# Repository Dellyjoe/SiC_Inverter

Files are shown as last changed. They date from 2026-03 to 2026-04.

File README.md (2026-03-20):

# SiC-Based Modular Inverter System
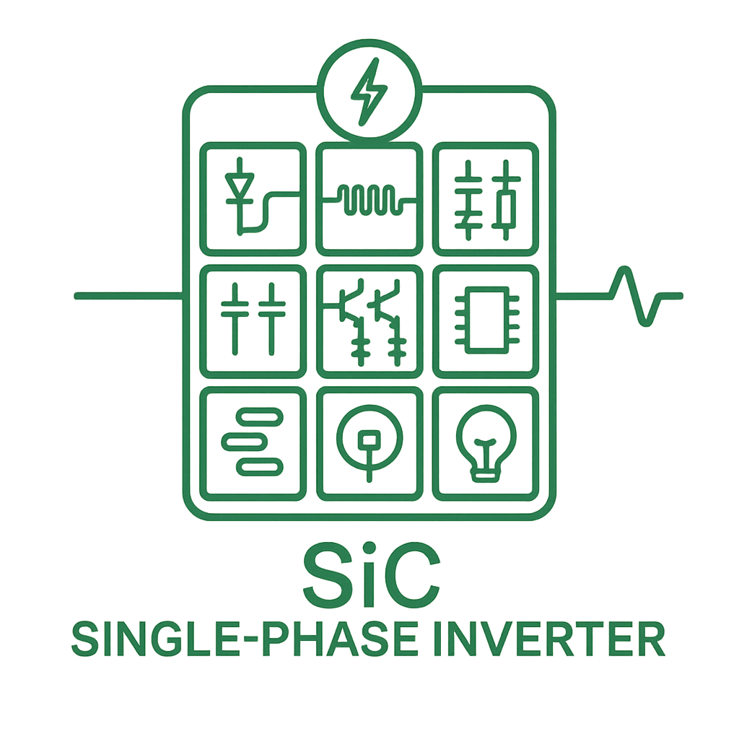
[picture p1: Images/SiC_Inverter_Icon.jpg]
SiC Icon


## Table of Contents
1. [Project Overview](#1-project-overview)  
2. [System Architecture](#2-system-architecture)  
   - [EMI Input Filter](#21-emi-input-filter)  
   - [Pre‑Charge & Inrush Limiting](#22-pre-charge--inrush-limiting)  
   - [DC‑Link Capacitor Network](#23-dc-link-capacitor-network)  
   - [Inverter Power Stage](#24-inverter-power-stage)  
   - [Output LCL Filter](#25-output-lcl-filter)  
3. [Electrical Specifications](#3-electrical-specifications)  
4. [Development Tools & Equipment](#4-development-tools--equipment)  
5. [Current Status](#5-current-status)  
6. [System Block Diagram](#6-system-block-diagram)

---

## 1. Project Overview

This project is a **modular, SiC‑based single‑phase inverter system** designed using professional engineering practices and a clean, hierarchical architecture. Each functional block is implemented as its own PCB, enabling:

- **Modularity** — swap, upgrade, or debug subsystems independently  
- **Scalability** — expand to higher power levels or new control architectures  
- **Serviceability** — isolate issues quickly during bring‑up  
- **Educational clarity** — each PCB teaches a specific power‑electronics concept  

Key design principles:

- **Hierarchical schematics** (KiCad 9)  
- **Modular PCBs** (EMI filter, pre‑charge, DC‑link, inverter legs, LCL filter, power supplies, controller)  
- **High‑performance SiC MOSFETs** for fast switching and low losses  
- **Low‑inductance DC‑link layout**  
- **Safe, lab‑friendly bring‑up** (initially 60 VDC)  

The long‑term goal is a **flexible, open inverter platform** suitable for experimentation, research, and future expansion.

---

## 2. System Architecture

The inverter is divided into well‑defined functional blocks.

### 2.1 EMI Input Filter
- Differential‑mode LC filter  
  - **L_DM:** `2300HT-470-H-RC`  
  - **C_IN:** `R71PI410050H6K`  
- Common‑mode choke: `7448258022`  
- Provides clean, low‑noise DC to downstream stages  
- **Outputs:** `BUS+_Filtered`, `BUS-_Filtered`

---

### 2.2 Pre‑Charge & Inrush Limiting
- Limits inrush current to **~5 A**  
- Uses an **80 Ω** pre‑charge resistor  
- MOSFET/relay bypass for full‑power operation  
- Interfaces between EMI filter and DC‑link  
- **Outputs:** `DC+`, `DC−`

---

### 2.3 DC‑Link Capacitor Network
- **Bulk Storage:** 220 µF electrolytic (10 × `ESH226M500AL4AA`)  
- **High‑Frequency Film:** 10 µF polypropylene (5 × `MKP1848C52050JK2`)  
- Provides:
  - Energy storage  
  - Low‑impedance switching current path  
  - Reduced ripple and overshoot  

---

### 2.4 Inverter Power Stage
- **Topology:** Full‑bridge using SiC MOSFET half‑bridge legs  
- **Switching Devices:** 4 × Wolfspeed `C3M0025065K`  
- **Gate Drivers:** 4 × TI `UCC21710QDWRQ1` isolated drivers  
- **Sensing:** Placeholders for output current and DC bus voltage (future work)  
- **Control:** PWM interface for microcontroller or DSP  

---

### 2.5 Output LCL Filter
- Shapes PWM into low‑distortion 60 Hz AC  
- Reduces switching ripple and protects the load  
- **Components:**
  - **Series Inductors:**  
    - `L1`: 470 µH (`Bourns 1140-471K-RC`)  
    - `L2`: 470 µH (`Bourns 1140-471K-RC`)  
  - **Shunt Capacitor:**  
    - `C_F`: 6.8 µF, 305 Vac MKP (`KEMET C4AF9BW4680T3FK`)  
  - **Damping Resistor:**  
    - `R_D`: ~10 Ω, ≥3 W (`TE 3-2176794-3`)  
- **Design Target:**  
  - Resonant frequency ≈ 2 kHz  
  - Damped to avoid resonance peaking  

---

## 3. Electrical Specifications

| Parameter | Value | Notes |
|---|---|---|
| **Input Voltage Range** | 335–425 VDC | |
| **Nominal DC Bus Voltage** | 400 VDC | |
| **Output Voltage** | 120 Vrms | Single‑phase AC |
| **Output Frequency** | 60 Hz | |
| **Continuous Power** | 500 W | |
| **Peak Power** | 1 kW | |
| **Continuous Current (RMS)** | 4.1 Arms | Output |
| **Continuous Current (DC)** | 1.25 A | Input at nominal voltage |
| **Switching Frequency** | 40 kHz | Initial target |
| **Target Inrush Current** | < 5 A | Pre‑charge limited |
| **DC‑Link Capacitance** | 220 µF electrolytic + 10 µF film | |
| **Capacitor Voltage Rating** | >500 V | |
| **Output Filter Topology** | LCL | 470 µH – 6.8 µF – 470 µH |

---

## 4. Development Tools & Equipment
- **CAD:** KiCad 9 (hierarchical design)  
- **Version Control:** Git  
- **Documentation:** draw.io, Markdown  
- **Bench Tools:** Oscilloscope, isolated supplies, differential probes  
- *(More tools will be added as the project grows)*  

---

## 5. Current Status

- [x] EMI filter — **Complete**  
- [x] Pre‑charge topology — **Defined**  
- [x] DC‑link architecture — **Defined**  
- [x] KiCad hierarchy — **Modular & clean**  
- [x] Pre‑charge components added  
- [x] DC‑link capacitor bank added  
- [x] Inverter leg schematic started  
- [x] Output LCL filter populated with real parts  
- [x] Inverter + LCL interaction reviewed in simulation  
- [x] Power‑stage support rails (+15V ISO, +3V3 logic)  
- [x] Controller selected  
- [ ] Controller wiring  
- [ ] Layout of sub‑PCBs  
- [ ] System wiring and integration  

---

## 6. System Block Diagram

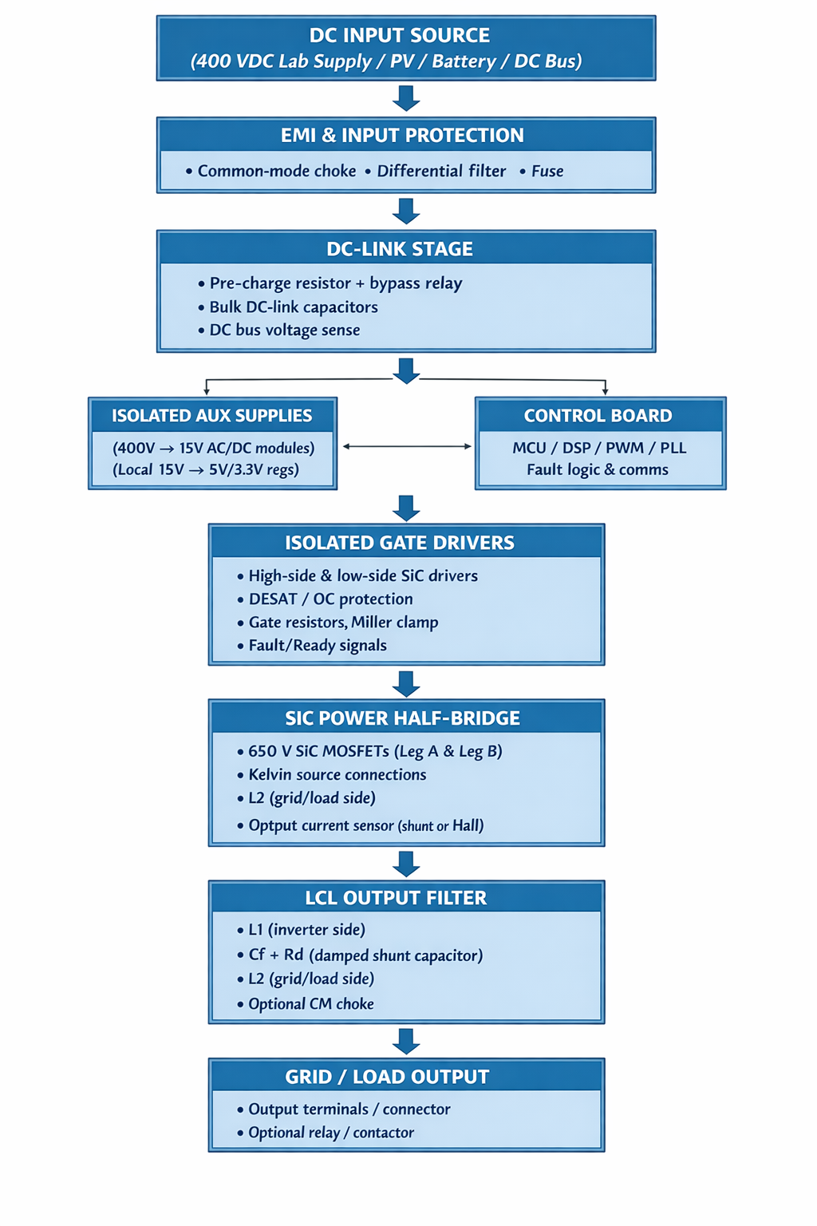
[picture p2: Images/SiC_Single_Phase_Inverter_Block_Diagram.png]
Block Diagram


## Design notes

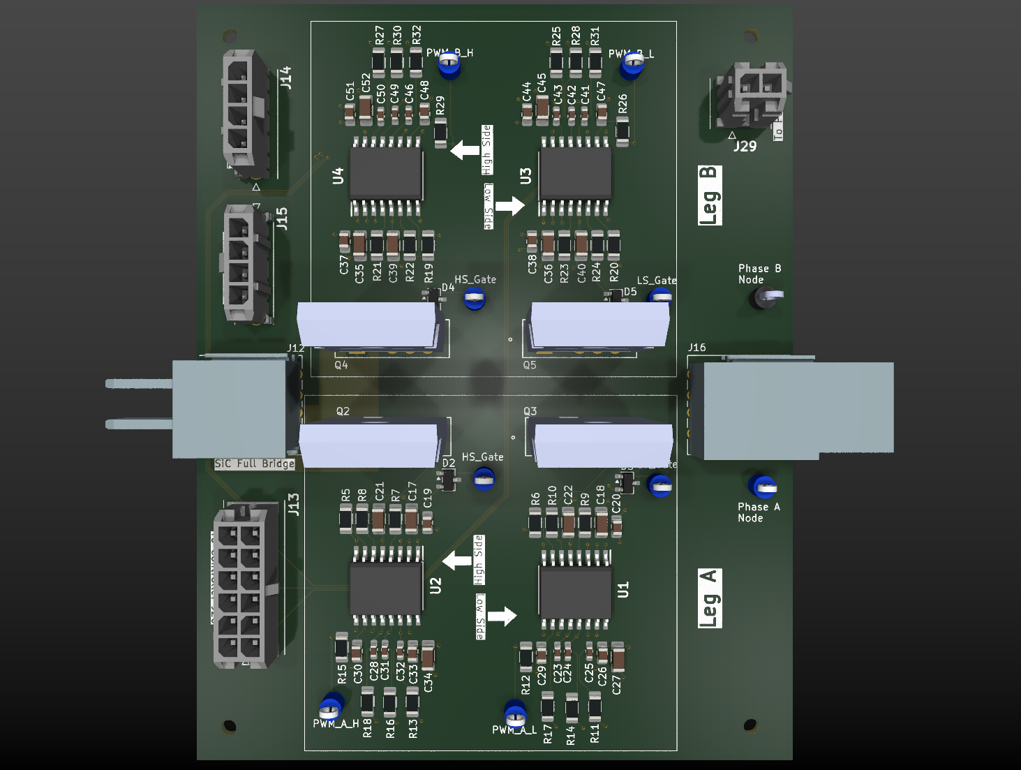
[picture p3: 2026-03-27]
Images/DC_input_Protection_PCB/Full-Bridge_PCB.png

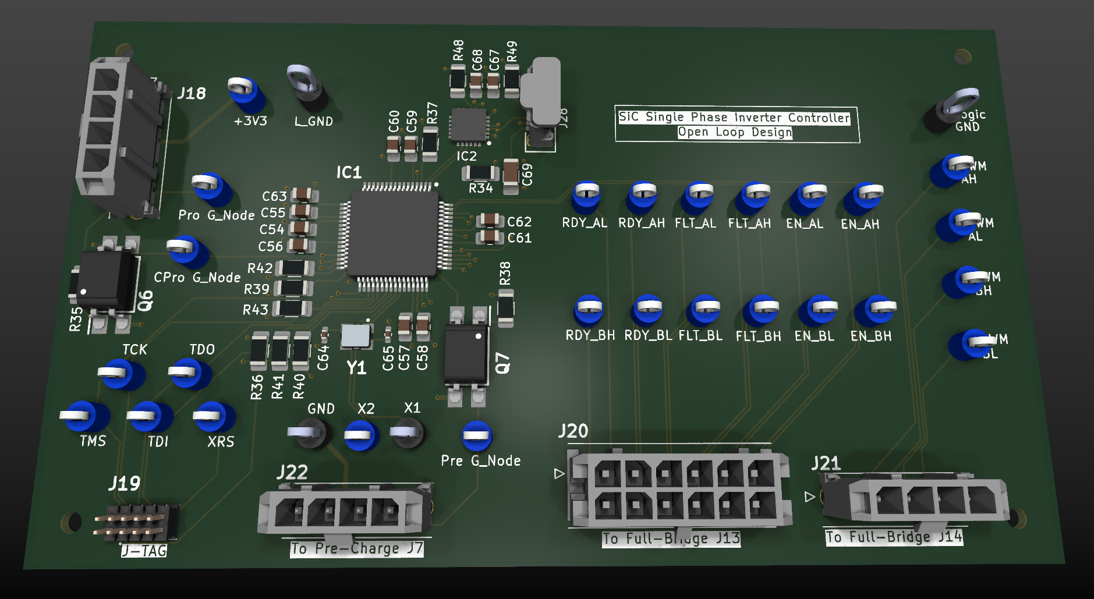
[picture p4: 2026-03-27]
Images/DC_input_Protection_PCB/Controller_Board_PCB.png

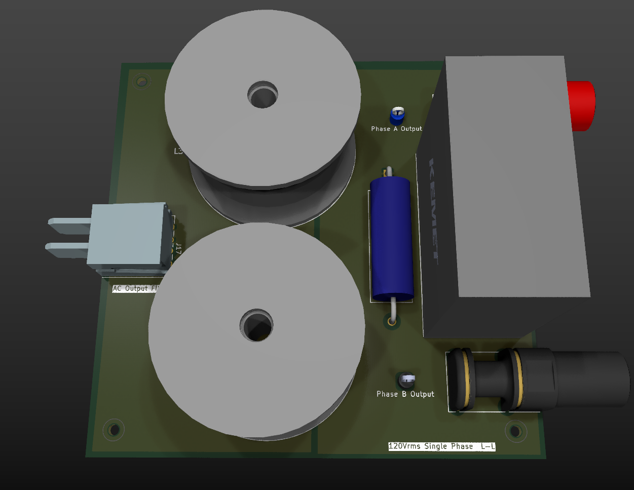
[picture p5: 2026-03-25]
Images/DC_input_Protection_PCB/AC_Output_Filter.png

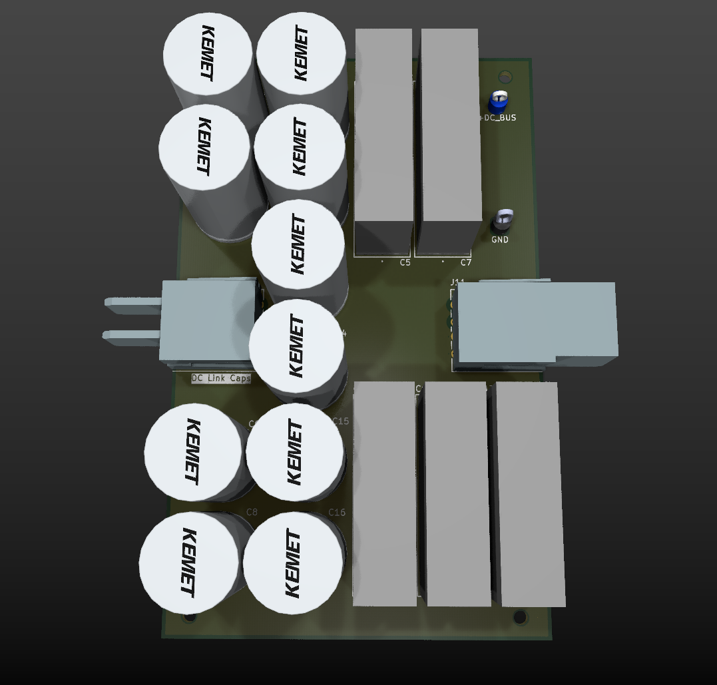
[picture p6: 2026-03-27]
Images/DC_input_Protection_PCB/DC_Link_caps.png

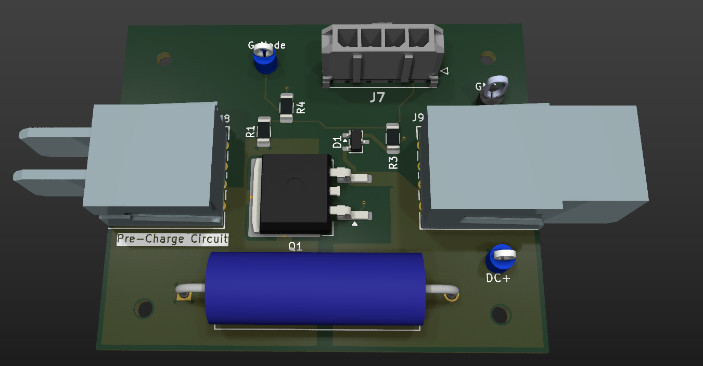
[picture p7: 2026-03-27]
Images/DC_input_Protection_PCB/Pre_Charge_Circuit.png

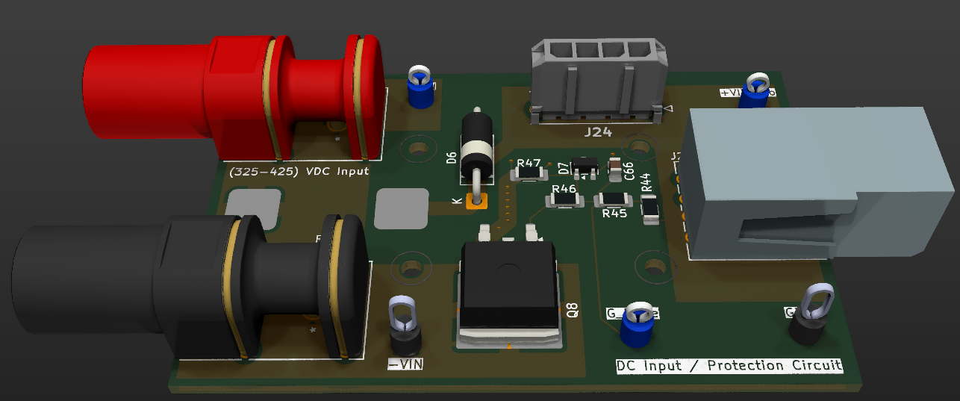
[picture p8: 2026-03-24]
Images/DC_input_Protection_PCB/DC_Input_ProtectionB1.0.png

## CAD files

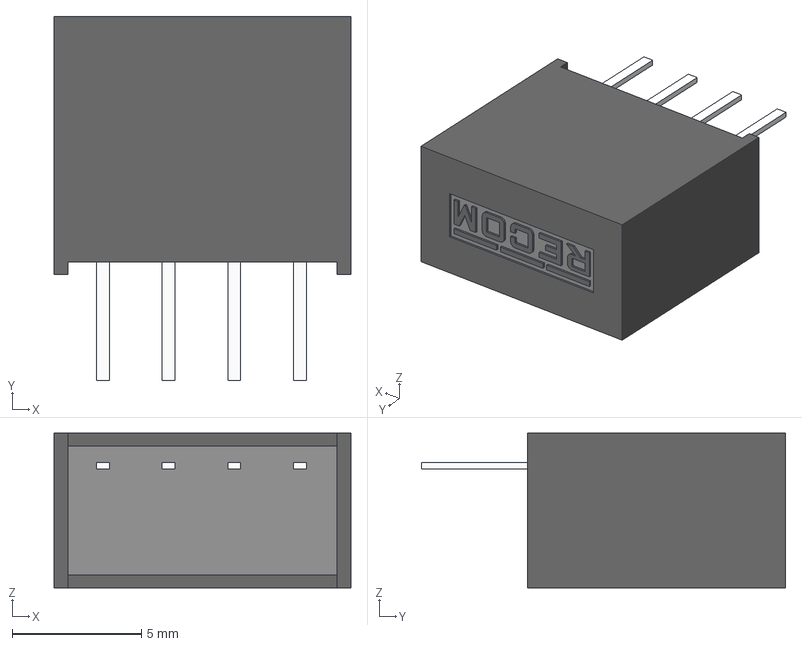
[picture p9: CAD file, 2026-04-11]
Schematics/3d-models/RO-153.3S_H.stp
11.5 x 14.1 x 6.00 mm

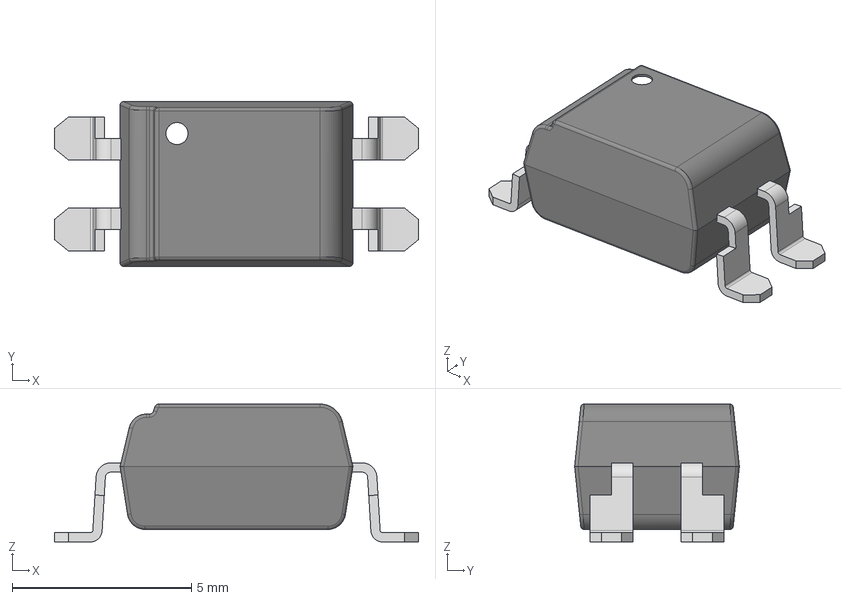
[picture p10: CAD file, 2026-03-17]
Schematics/Sub_PCB_Sheets/AC_Output_Filter/3d-models/PC817X1CSP9F.stp
10.2 x 4.60 x 3.85 mm

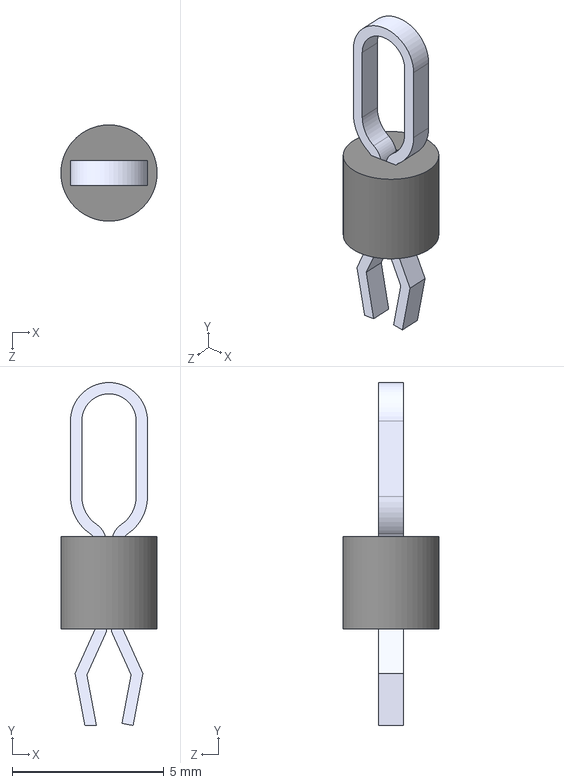
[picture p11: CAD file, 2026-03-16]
Schematics/Sub_PCB_Sheets/AC_Output_Filter/3d-models/5281.stp
3.17 x 11.3 x 3.17 mm

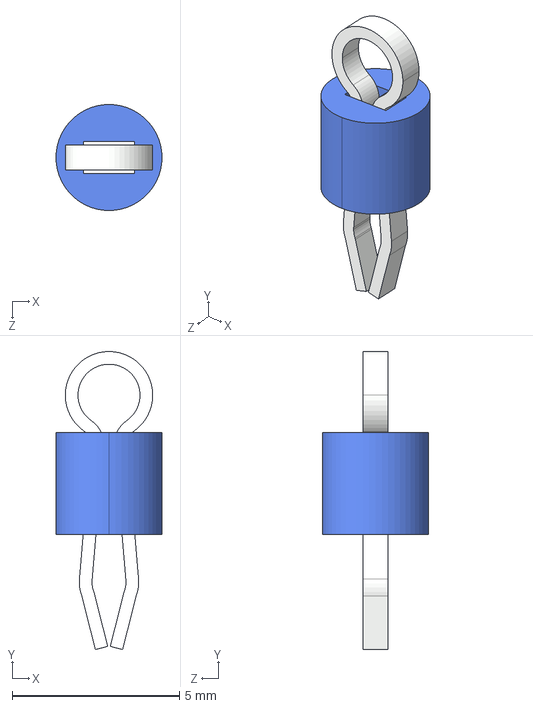
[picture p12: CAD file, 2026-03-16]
Schematics/Sub_PCB_Sheets/DC_Link_Caps/3d-models/5277.stp
3.17 x 8.92 x 3.17 mm

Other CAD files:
Schematics/3d-models/43045-0212.stp
Schematics/Sub_PCB_Sheets/AC_Output_Filter/3d-models/0464369202.stp
Schematics/Sub_PCB_Sheets/AC_Output_Filter/3d-models/0464379202.stp
Schematics/Sub_PCB_Sheets/AC_Output_Filter/3d-models/105133-0011.stp
Schematics/Sub_PCB_Sheets/AC_Output_Filter/3d-models/1140-471K-RC.stp
Schematics/Sub_PCB_Sheets/AC_Output_Filter/3d-models/2300HT-470-H-RC.stp
Schematics/Sub_PCB_Sheets/AC_Output_Filter/3d-models/43045-1212.stp
Schematics/Sub_PCB_Sheets/AC_Output_Filter/3d-models/43650-0418.stp
Schematics/Sub_PCB_Sheets/AC_Output_Filter/3d-models/66.9040-21_Black.stp
Schematics/Sub_PCB_Sheets/AC_Output_Filter/3d-models/66.9040-22_Red.stp
Schematics/Sub_PCB_Sheets/AC_Output_Filter/3d-models/ABM8-20.000MHZ-B2-T.stp
Schematics/Sub_PCB_Sheets/AC_Output_Filter/3d-models/C3M0025065K.stp
Schematics/Sub_PCB_Sheets/AC_Output_Filter/3d-models/C4AF9BW4680T3FK.stp
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

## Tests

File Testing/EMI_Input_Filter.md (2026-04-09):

# EMI Input Filter – Testing Document

## 1. Overview

This document captures the test procedure, setup, and measured performance of the EMI Input Filter used between `+VIN_EMI` and `BUS+_Filtered`.  
The filter consists of:

- **L1 = 47 µH** (series)
- **C1 = 1 µF** (shunt to GND)
- **L2 = 2.2 mH** (series)(CMC)

This forms a two‑stage differential‑mode LC low‑pass filter intended to suppress inverter switching noise from propagating back toward the DC source.

---

## 2. Test Equipment

- **Function Generator**
  - Sine wave output
  - 1 Vpp amplitude
  - Output load set to **High‑Z / 1 MΩ**
- **Oscilloscope**
  - Two channels (CH1 = Vin, CH2 = Vout)
  - DC coupling
  - Matching probe attenuation (1×)
---

## 3. Test Setup

### Connections

- Function Gen `+` → `+VIN_EMI`
- Function Gen `−` → GND
- Scope CH1 → `+VIN_EMI`
- Scope CH2 → `BUS+_Filtered`
- Scope grounds → GND

### Notes
- Verify the function generator produces the correct amplitude by connecting it directly to the scope before testing the filter.
---

## 4. Test Procedure

1. **Baseline Verification**
   - Set function generator to **1 kHz, 1 Vpp**.
   - Confirm **Vin ≈ Vout** (flat passband behavior).

2. **Frequency Sweep**
   - Keep amplitude at **1 Vpp**.
   - Measure Vin and Vout at the following frequencies:
     - 0.01 kHz  
     - 0.1 kHz  
     - 1 kHz  
     - 10 kHz  
     - 50 kHz  
     - 100 kHz  
     - 200 kHz  
     - 500 kHz  
     - 1000 kHz (1 MHz)

3. **Record Data**
   - Capture Vin (Vpp), Vout (Vpp), and compute attenuation.

---

## 5. Measured Results

### Raw Data

| Freq (kHz) | Vin (Vpp) | Vout (Vpp) |
|---:|---|---|
| 0.01 | 1.000 V | 1.000 V |
| 0.1 | 0.983 V | 0.999 V |
| 1 | 0.378 V | 0.378 V |
| 10 | 0.034 V | 0.042 V |
| 50 | 0.030 V | 0.010 V |
| 100 | 0.071 V | 0.0057 V |
| 200 | 0.148 V | 0.0020 V |
| 500 | 0.390 V | 0.0015 V |
| 1000 | 0.810 V | 0.0012 V |

### Calculated Attenuation

| Freq (kHz) | Vout/Vin | Attenuation (dB) |
|---:|---|---|
| 0.01 | 1.00 | 0.0 dB |
| 0.1 | 1.02 | +0.2 dB |
| 1 | 1.00 | 0.0 dB |
| 10 | 1.24 | +1.9 dB |
| 50 | 0.33 | −9.6 dB |
| 100 | 0.08 | −22.0 dB |
| 200 | 0.0135 | −37.4 dB |
| 500 | 0.00385  | −48.3 dB |
| 1000 | 0.00148  | −56.6 dB |

---

## 6. Interpretation

### Passband (0–1 kHz)
- Filter is flat and stable.
- No significant attenuation.
- Suitable for inverter low‑frequency bus ripple and control‑loop dynamics.

### Transition Region (10–50 kHz)
- Begins attenuating around 10–20 kHz.
- ~−10 dB by 50 kHz.

### Stopband (100 kHz–1 MHz)
- Strong attenuation:
  - ~−22 dB at 100 kHz  
  - ~−37 dB at 200 kHz  
  - ~−48 dB at 500 kHz  
  - ~−57 dB at 1 MHz  
---

## 7. Practical Impact on the System

If the inverter produces ~1 Vpp differential‑mode ripple on the DC bus:

- At **50 kHz** → ~0.33 Vpp reaches +VIN_EMI  
- At **100 kHz** → ~80 mVpp  
- At **200 kHz** → ~13 mVpp  
- At **500 kHz** → ~4 mVpp  
- At **1 MHz** → ~1.5 mVpp  

This significantly reduces conducted noise back into the power supply or battery.

---

## 8. Conclusion

The EMI Input Filter performs as designed:

- Flat response in the operating band (0–1 kHz)
- Strong attenuation in the inverter switching band (50–200 kHz)
- Very deep attenuation at high harmonics (500 kHz–1 MHz)

This filter will effectively prevent inverter switching noise from contaminating the upstream DC source.

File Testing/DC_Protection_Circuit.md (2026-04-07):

# DC Input Protection Circuit – Test Notes

## 1. Test Setup

- Bench Supply: Riden RD6018W  

- Connections

&#x20; - RD6018W `+` → `+VIN`

&#x20; - RD6018W `−` → `−VIN` (GND)

### Circuit Under Test

&#x20; - F1 fuse

&#x20; - D6 (P6KE500A TVS)

&#x20; - Q8 (STB10NK60Z) N‑MOSFET

&#x20; - Gate network: R44, R45, R46, R47, C66, D7 (zener)

&#x20; - Output node: `+VIN\_Protected`

---

## 2. Forward‑Polarity, No‑Load Tests

Needs to be completed

### Conditions
- No load connected to `+VIN\_Protected`.

### VGS Measurements

| VIN | VGS |

|-----|------|

| 12 V | \~1.05 V |

| 48 V | \~4.34 V |

| 60 V | \~5.42 V |

### Interpretation

- Gate voltage scales at \~9% of VIN (below zener clamp region).

- MOSFET is weakly enhanced at low VIN and more enhanced at higher VIN.

---

## 3. Forward‑Polarity, No‑Load VDS (Voltage Drop Across Q8)

### Definition

`VDS = VIN − VIN\_Protected`

### VDS Measurements

| VIN | VDS |
|-----|---|
| 12 V | ~0.225 V  |
| 48 V | ~0.001 V  |
| 60 V | ~0 V |

### Interpretation

- At higher VIN, Q8 behaves as a low‑loss pass element.

- Small drop at 12 V is expected and acceptable with no load.

## 4. Reverse‑Polarity Test

### Setup

RD6018W leads intentionally reversed:

- RD6018W `+` → `−VIN`

- RD6018W `−` → `+VIN`

### Observations

- No output voltage on `+VIN\_Protected`.

- No abnormal current draw from RD6018W.

### Conclusion

Reverse‑polarity protection works correctly.  

Q8 blocks reverse conduction and TVS does not falsely trigger.

## 5. Gate Clamp Behavior (Conceptual)

- Gate network is a resistor divider + zener clamp (D7).

- Below zener knee 

&#x20; Gate ≈ 9% of VIN (matches measured VGS at 12–60 V).

- \*\*Above zener knee:\*\*  

&#x20; VGS is clamped near zener voltage (\~15 V).  

&#x20; Excess voltage is dissipated through the divider + zener.

### Implication  

Gate oxide is protected from overvoltage.  

Divider + zener must be power‑rated appropriately if VIN increases.

## 6. Voltage Range and Safety Notes

- Circuit has been tested and validated up to \*\*60 V\*\* using RD6018W.

- Component choices and PCB layout indicate a \*\*low‑voltage DC input stage\*\*.

- Even though Q8 is a 600 V MOSFET and D6 is a 500 V TVS:

 - PCB creepage/clearance is not rated for 400 V.

 - Fuse breaking capacity is not rated for high‑energy HV faults.

- Gate divider would force significant current into the zener at high VIN.

### Conclusion

This design should \*\*not\*\* be used above \~60–80 V without redesign.

## 7. Next Planned Tests (With Load)

Once power resistors are available

1\. Add loads to `+VIN\_Protected`:

- 100 Ω, 47 Ω, 22 Ω (50–100 W resistors)

2\. For each VIN (12 V, 24 V, 48 V, 60 V):

  - Record \*\*VIN\*\*

  - Record \*\*load value\*\*

  - Record \*\*current (I)\*\* from RD6018W

  - Measure \*\*VDS (VIN − VIN\_Protected)\*\*

  - Check Q8 temperature (touch/IR/thermocouple)

# Goal

Verify Q8 dissipation under load and confirm the input stage is ready for inverter bring‑up.

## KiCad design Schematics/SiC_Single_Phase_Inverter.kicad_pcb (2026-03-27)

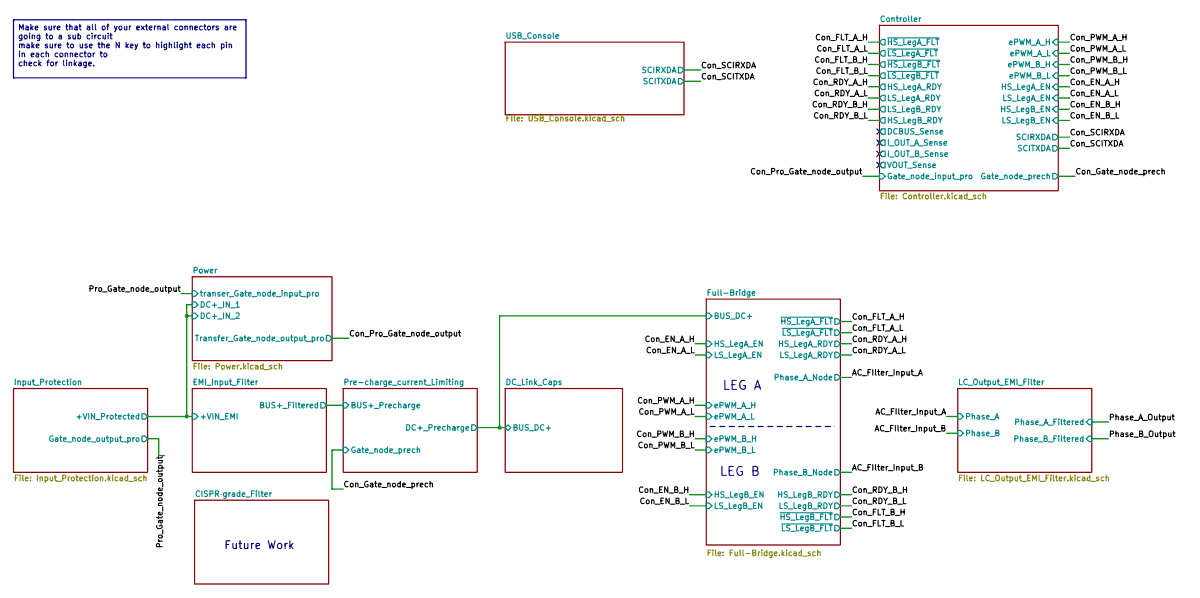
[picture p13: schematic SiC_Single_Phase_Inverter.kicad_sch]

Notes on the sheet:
LEG B
Future Work
LEG A
Make sure that all of your external connectors are going to a sub circuit make sure to use the N key to highlight each pin in each connector to check for linkage.

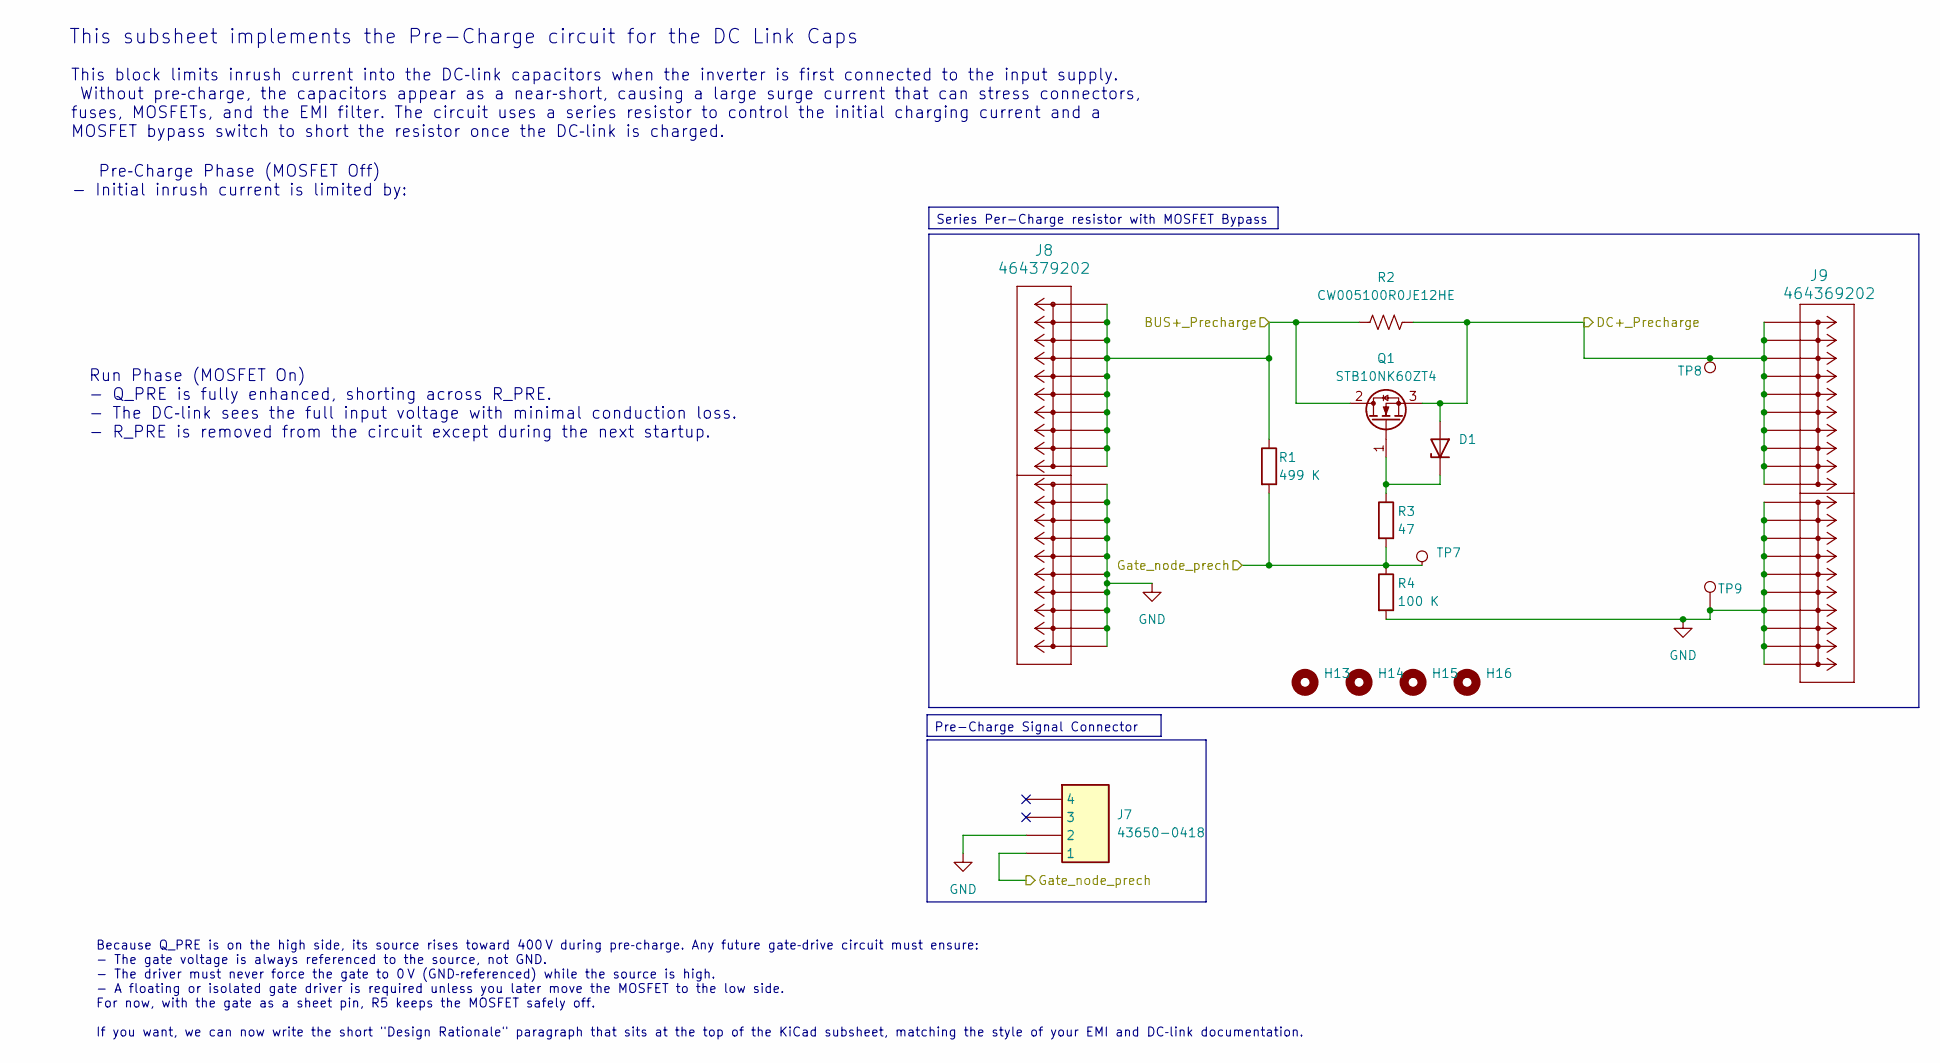
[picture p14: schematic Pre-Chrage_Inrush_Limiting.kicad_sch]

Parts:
D1: BZX84C15-7-F; SOT-23-3
H13, H14, H15, H16: MountingHole; MountingHole_2.2mm_M2
J7: 43650-0418; 436500418; Mouser Part Number 538-43650-0418
J8: 464379202; 46437-900_02
J9: 464369202; 46436-900_02
Q1: STB10NK60ZT4; TO-263-2
R1: 499 K; R_1206_3216Metric_Pad1.30x1.75mm_HandSolder
R2: CW005100R0JE12HE
R3: 47; R_1206_3216Metric_Pad1.30x1.75mm_HandSolder
R4: 100 K; R_1206_3216Metric_Pad1.30x1.75mm_HandSolder
TP7, TP8: 5277
TP9: 5281

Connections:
/Con_Gate_node_prech: J7.1, R1.2, R3.2, R4.1, TP7.1 (1_1); also elsewhere on the board
/DC_Link_Caps/BUS_DC+: D1.2 (A), J9.P1_1, J9.P1_2, J9.P1_3, J9.P1_4, J9.P1_5, J9.P1_6, J9.P1_7, J9.P1_8, J9.P1_9, J9.P1_10, Q1.3, R2.2, TP8.1 (1_1); also elsewhere on the board
/EMI_Input_Filter/BUS+_Filtered: J8.P2_1, J8.P2_2, J8.P2_3, J8.P2_4, J8.P2_5, J8.P2_6, J8.P2_7, J8.P2_8, J8.P2_9, J8.P2_10, Q1.2, R1.1, R2.1; also elsewhere on the board
GND: J7.2, J8.P1_1, J8.P1_2, J8.P1_3, J8.P1_4, J8.P1_5, J8.P1_6, J8.P1_7, J8.P1_8, J8.P1_9, J8.P1_10, J9.P2_1, J9.P2_2, J9.P2_3, J9.P2_4, J9.P2_5, J9.P2_6, J9.P2_7, J9.P2_8, J9.P2_9, J9.P2_10, R4.2, TP9.1 (1_1); also elsewhere on the board
unnamed: D1.1 (K), Q1.1 (G), R3.1

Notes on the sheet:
This block limits inrush current into the DC‑link capacitors when the inverter is first connected to the input supply. Without pre‑charge, the capacitors appear as a near‑short, causing a large surge current that can stress connectors, fuses, MOSFETs, and the EMI filter. The circuit uses a series r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
Pre‑Charge Phase (MOSFET Off) - Initial inrush current is limited by:
This subsheet implements the Pre-Charge circuit for the DC Link Caps
Run Phase (MOSFET On) - Q_PRE is fully enhanced, shorting across R_PRE. - The DC‑link sees the full input voltage with minimal conduction loss. - R_PRE is removed from the circuit except during the next startup.
Because Q_PRE is on the high side, its source rises toward 400 V during pre‑charge. Any future gate‑drive circuit must ensure: - The gate voltage is always referenced to the source, not GND. - The driver must never force the gate to 0 V (GND‑referenced) while the source is high. - A floating or iso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
Series Per-Charge resistor with MOSFET Bypass
Pre-Charge Signal Connector

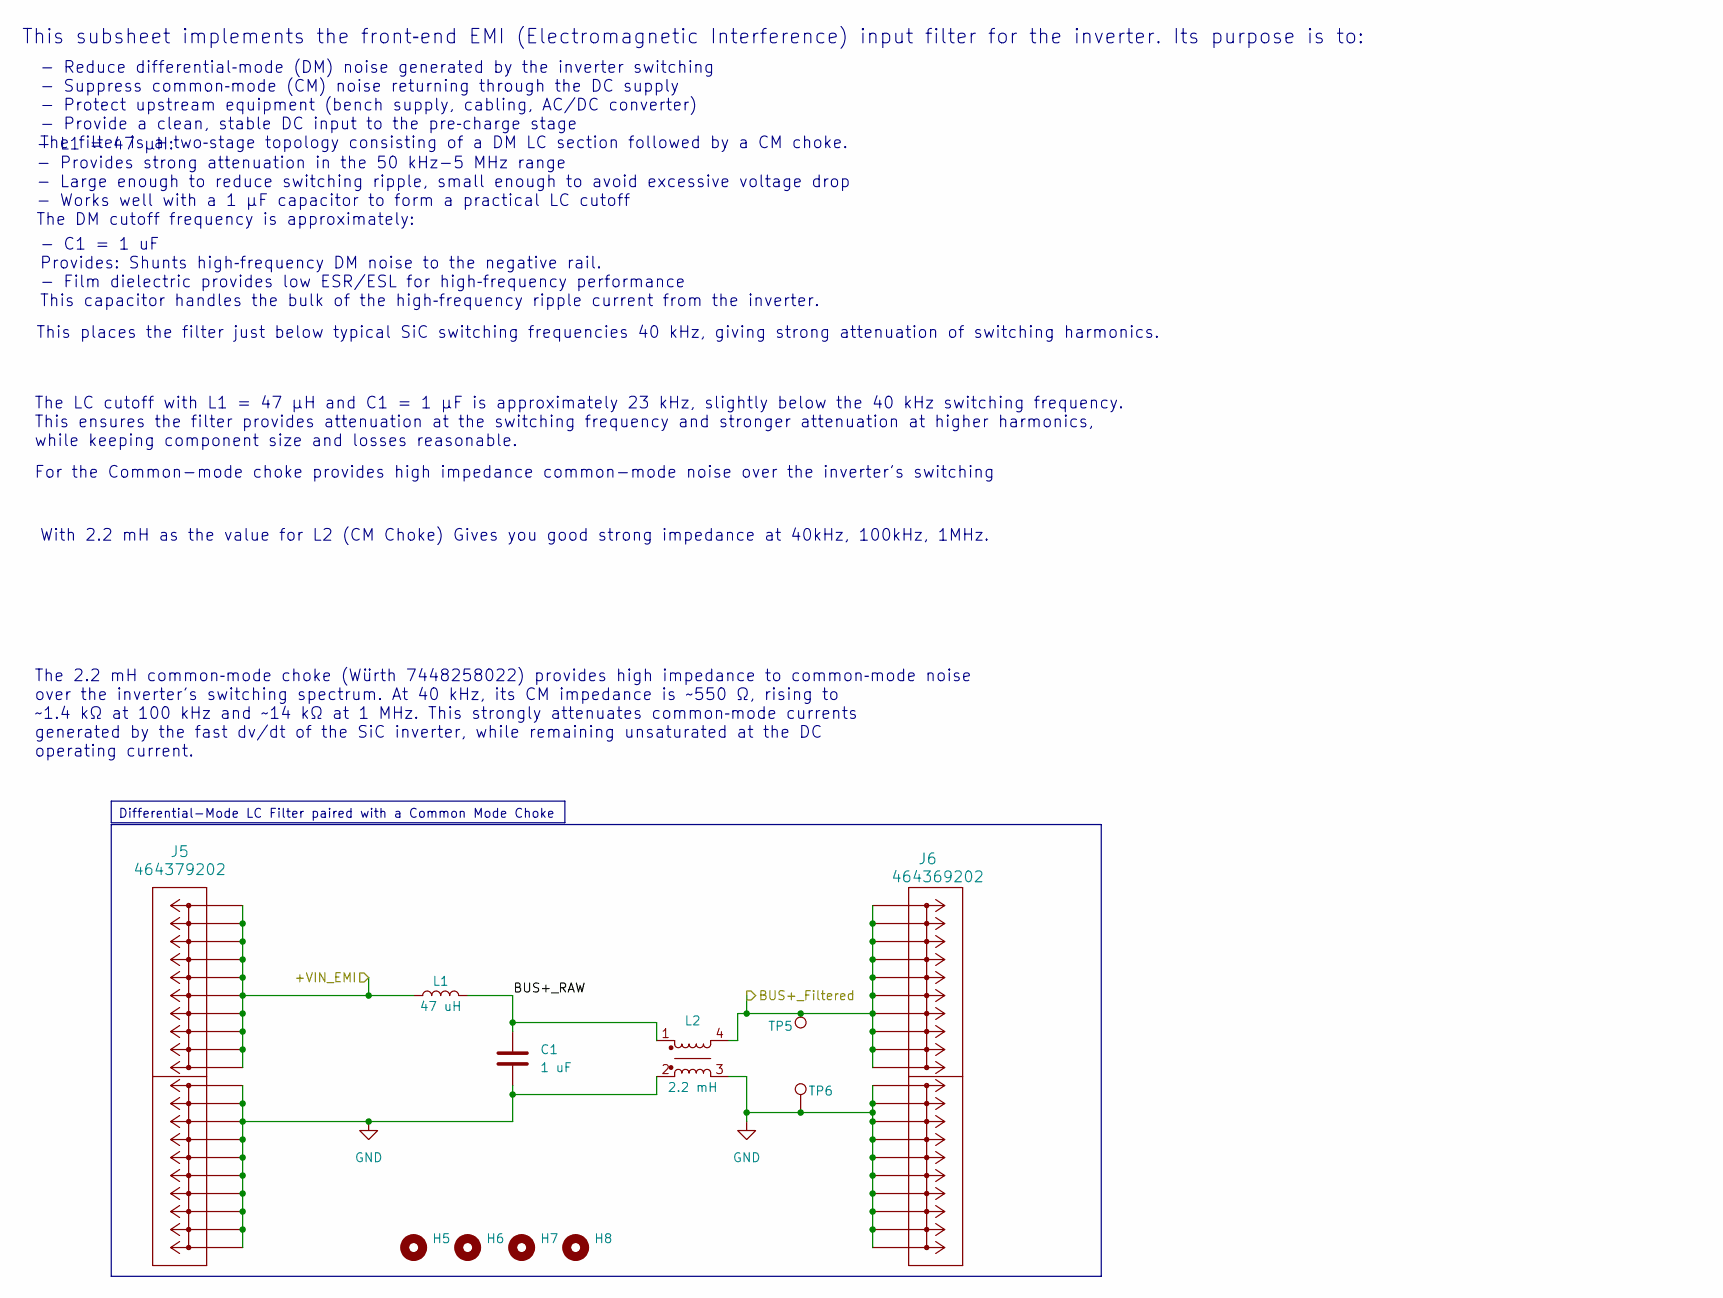
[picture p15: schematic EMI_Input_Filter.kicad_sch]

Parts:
C1: 1 uF; R71PI410050H6K
H5, H6, H7, H8: MountingHole; MountingHole_2.2mm_M2
J5: 464379202; 46437-900_02
J6: 464369202; 46436-900_02
L1: 47 uH; 2300HT_470
L2: 2.2 mH; 7448258022
TP5: 5277
TP6: 5281

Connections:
/EMI_Input_Filter/+VIN_EMI: J5.P2_1, J5.P2_2, J5.P2_3, J5.P2_4, J5.P2_5, J5.P2_6, J5.P2_7, J5.P2_8, J5.P2_9, J5.P2_10, L1.1; also elsewhere on the board
/EMI_Input_Filter/BUS+_Filtered: J6.P1_1, J6.P1_2, J6.P1_3, J6.P1_4, J6.P1_5, J6.P1_6, J6.P1_7, J6.P1_8, J6.P1_9, J6.P1_10, L2.4, TP5.1 (1_1); also elsewhere on the board
/EMI_Input_Filter/BUS+_RAW: C1.1, L1.2, L2.1
GND: C1.2, J5.P1_1, J5.P1_2, J5.P1_3, J5.P1_4, J5.P1_5, J5.P1_6, J5.P1_7, J5.P1_8, J5.P1_9, J5.P1_10, J6.P2_1, J6.P2_2, J6.P2_3, J6.P2_4, J6.P2_5, J6.P2_6, J6.P2_7, J6.P2_8, J6.P2_9, J6.P2_10, L2.2, L2.3, TP6.1 (1_1); also elsewhere on the board

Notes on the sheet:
This subsheet implements the front‑end EMI (Electromagnetic Interference) input filter for the inverter. Its purpose is to:
- L1 = 47 µH: - Provides strong attenuation in the 50 kHz-5 MHz range - Large enough to reduce switching ripple, small enough to avoid excessive voltage drop - Works well with a 1 µF capacitor to form a practical LC cutoff The DM cutoff frequency is approximately: This places the filter just below 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
- Reduce differential‑mode (DM) noise generated by the inverter switching - Suppress common‑mode (CM) noise returning through the DC supply - Protect upstream equipment (bench supply, cabling, AC/DC converter) - Provide a clean, stable DC input to the pre‑charge stage The filter is a two‑stage topo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
The 2.2 mH common‑mode choke (Würth 7448258022) provides high impedance to common‑mode noise over the inverter's switching spectrum. At 40 kHz, its CM impedance is ~550 Ω, rising to ~1.4 kΩ at 100 kHz and ~14 kΩ at 1 MHz. This strongly attenuates common‑mode currents generated by the fast dv/dt of 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
The LC cutoff with L1 = 47 µH and C1 = 1 µF is approximately 23 kHz, slightly below the 40 kHz switching frequency. This ensures the filter provides attenuation at the switching frequency and stronger attenuation at higher harmonics, while keeping component size and losses reasonable.
For the Common-mode choke provides high impedance common-mode noise over the inverter's switching
With 2.2 mH as the value for L2 (CM Choke) Gives you good strong impedance at 40kHz, 100kHz, 1MHz.
- C1 = 1 uF Provides: Shunts high‑frequency DM noise to the negative rail. - Film dielectric provides low ESR/ESL for high‑frequency performance This capacitor handles the bulk of the high‑frequency ripple current from the inverter.
Differential-Mode LC Filter paired with a Common Mode Choke

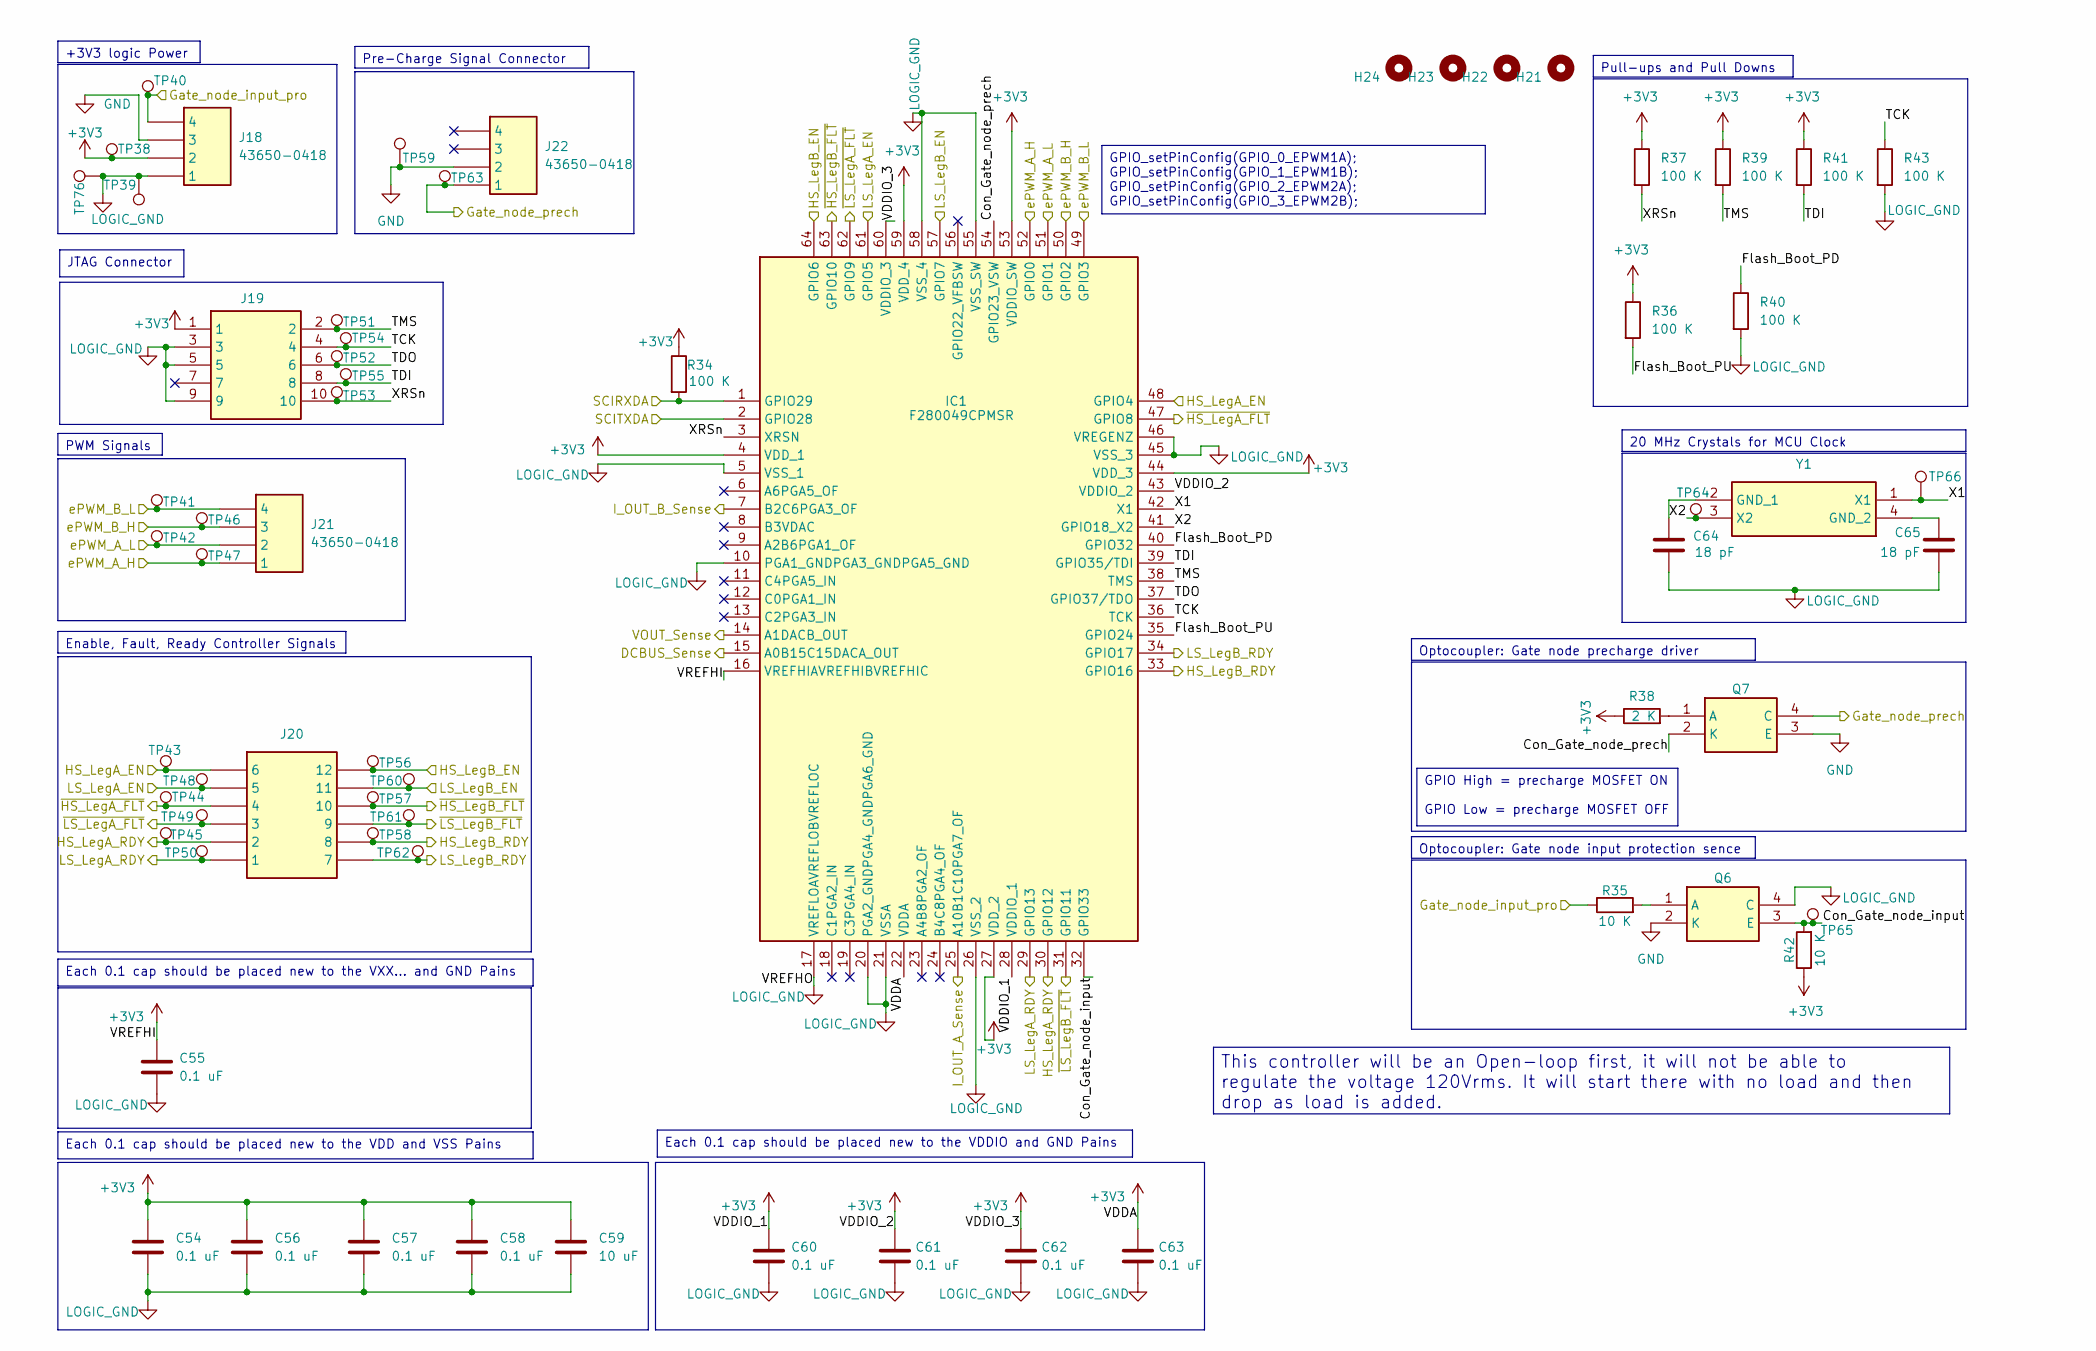
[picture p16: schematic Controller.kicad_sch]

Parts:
C54, C55, C56, C57, C58, C60, C61, C62, C63: 0.1 uF; C_0805_2012Metric_Pad1.18x1.45mm_HandSolder
C59: 10 uF; C_0805_2012Metric_Pad1.18x1.45mm_HandSolder
C64, C65: 18 pF; C_0402_1005Metric_Pad0.74x0.62mm_HandSolder
H21, H22, H23, H24: MountingHole; MountingHole_2.2mm_M2
IC1: F280049CPMSR; Mouser Part Number 595-F280049CPMSR
J18, J21, J22: 43650-0418; 436500418; Mouser Part Number 538-43650-0418
J19: FTSH-105-01-LM-D-K; Manufacturer_Part_Number FTSH-105-01-LM-D-K
J20: 43045-1212; Mouser Part Number 538-43045-1212
Q6, Q7: PC817X1CSP9F; Mouser Part Number 852-PC817X1CSP9F
R34, R36, R37, R39, R40, R41, R43: 100 K; R_1206_3216Metric_Pad1.30x1.75mm_HandSolder
R35, R42: 10 K; R_1206_3216Metric_Pad1.30x1.75mm_HandSolder
R38: 2 K; R_1206_3216Metric_Pad1.30x1.75mm_HandSolder
TP38, TP40, TP41, TP42, TP43, TP44, TP45, TP46, TP47, TP48, TP49, TP50, TP51, TP52, TP53, TP54, TP55, TP56, TP57, TP58, TP60, TP61, TP62, TP63, TP64, TP65: 5277
TP39, TP59, TP66, TP76: 5281
Y1: ABM8-20.000MHZ-B2-T; Mouser Part Number 815-ABM8-20-B2-T

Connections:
+3V3: C54.1, C55.1, C56.1, C57.1, C58.1, C59.1, C60.1, C61.1, C62.1, C63.1, IC1.4 (VDD_1), IC1.16 (VREFHIAVREFHIBVREFHIC), IC1.22 (VDDA), IC1.27 (VDD_2), IC1.28 (VDDIO_1), IC1.43 (VDDIO_2), IC1.44 (VDD_3), IC1.53 (VDDIO_SW), IC1.59 (VDD_4), IC1.60 (VDDIO_3), J18.2, J19.1, R34.1, R36.1, R37.1, R38.1, R39.1, R41.1, R42.1, TP38.1 (1_1); also elsewhere on the board
/Con_EN_A_H: IC1.48 (GPIO4), J20.6, TP43.1 (1_1); also elsewhere on the board
/Con_EN_A_L: IC1.61 (GPIO5), J20.5, TP48.1 (1_1); also elsewhere on the board
/Con_EN_B_H: IC1.64 (GPIO6), J20.12, TP56.1 (1_1); also elsewhere on the board
/Con_EN_B_L: IC1.57 (GPIO7), J20.11, TP60.1 (1_1); also elsewhere on the board
/Con_FLT_A_H: IC1.47 (GPIO8), J20.4, TP44.1 (1_1); also elsewhere on the board
/Con_FLT_A_L: IC1.62 (GPIO9), J20.3, TP49.1 (1_1); also elsewhere on the board
/Con_FLT_B_H: IC1.63 (GPIO10), J20.10, TP57.1 (1_1); also elsewhere on the board
/Con_FLT_B_L: IC1.31 (GPIO11), J20.9, TP61.1 (1_1); also elsewhere on the board
/Con_Gate_node_prech: J22.1, Q7.4 (C), TP63.1 (1_1); also elsewhere on the board
/Con_PWM_A_H: IC1.52 (GPIO0), J21.1, TP47.1 (1_1); also elsewhere on the board
/Con_PWM_A_L: IC1.51 (GPIO1), J21.2, TP42.1 (1_1); also elsewhere on the board
/Con_PWM_B_H: IC1.50 (GPIO2), J21.3, TP46.1 (1_1); also elsewhere on the board
/Con_PWM_B_L: IC1.49 (GPIO3), J21.4, TP41.1 (1_1); also elsewhere on the board
/Con_Pro_Gate_node_output: J18.4, R35.1, TP40.1 (1_1); also elsewhere on the board
/Con_RDY_A_H: IC1.30 (GPIO12), J20.2, TP45.1 (1_1); also elsewhere on the board
/Con_RDY_A_L: IC1.29 (GPIO13), J20.1, TP50.1 (1_1); also elsewhere on the board
/Con_RDY_B_H: IC1.34 (GPIO17), J20.7, TP62.1 (1_1); also elsewhere on the board
/Con_RDY_B_L: IC1.33 (GPIO16), J20.8, TP58.1 (1_1); also elsewhere on the board
/Con_SCIRXDA: IC1.1 (GPIO29), R34.2; also elsewhere on the board
/Con_SCITXDA: IC1.2 (GPIO28); also elsewhere on the board
/Controller/Con_Gate_node_input: IC1.32 (GPIO33), Q6.3 (E), R42.2, TP65.1 (1_1)
/Controller/Con_Gate_node_prech: IC1.54 (GPIO23_VSW), Q7.2 (K)
/Controller/DCBUS_Sense: IC1.15 (A0B15C15DACA_OUT)
/Controller/Flash_Boot_PD: IC1.40 (GPIO32), R40.1
/Controller/Flash_Boot_PU: IC1.35 (GPIO24), R36.2
/Controller/I_OUT_A_Sense: IC1.25 (A10B1C10PGA7_OF)
/Controller/I_OUT_B_Sense: IC1.7 (B2C6PGA3_OF)
/Controller/TCK: IC1.36 (TCK), J19.4, R43.1, TP54.1 (1_1)
/Controller/TDI: IC1.39 (GPIO35/TDI), J19.8, R41.2, TP55.1 (1_1)
/Controller/TDO: IC1.37 (GPIO37/TDO), J19.6, TP52.1 (1_1)
/Controller/TMS: IC1.38 (TMS), J19.2, R39.2, TP51.1 (1_1)
/Controller/VOUT_Sense: IC1.14 (A1DACB_OUT)
/Controller/X1: IC1.42 (X1), TP66.1 (1_1), Y1.1 (X1)
/Controller/X2: IC1.41 (GPIO18_X2), TP64.1 (1_1), Y1.3 (X2)
/Controller/XRSn: IC1.3 (XRSN), J19.10, R37.2, TP53.1 (1_1)
GND: J18.3, J22.2, Q6.2 (K), Q7.3 (E), TP59.1 (1_1); also elsewhere on the board
LOGIC_GND: C54.2, C55.2, C56.2, C57.2, C58.2, C59.2, C60.2, C61.2, C62.2, C63.2, C64.2, C65.2, IC1.5 (VSS_1), IC1.10 (PGA1_GNDPGA3_GNDPGA5_GND), IC1.17 (VREFLOAVREFLOBVREFLOC), IC1.20 (PGA2_GNDPGA4_GNDPGA6_GND), IC1.21 (VSSA), IC1.26 (VSS_2), IC1.45 (VSS_3), IC1.46 (VREGENZ), IC1.55 (VSS_SW), IC1.58 (VSS_4), J18.1, J19.3, J19.5, J19.9, Q6.4 (C), R40.2, R43.2, TP39.1 (1_1), TP76.1 (1_1); also elsewhere on the board
unnamed: Q6.1 (A), R35.2
unnamed: Q7.1 (A), R38.2
unnamed: C64.1, Y1.2 (GND_1)
unnamed: C65.1, Y1.4 (GND_2)

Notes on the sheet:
Pull-ups and Pull Downs
GPIO_setPinConfig(GPIO_0_EPWM1A); GPIO_setPinConfig(GPIO_1_EPWM1B); GPIO_setPinConfig(GPIO_2_EPWM2A); GPIO_setPinConfig(GPIO_3_EPWM2B);
Pre-Charge Signal Connector
Each 0.1 cap should be placed new to the VDDIO and GND Pains
Enable, Fault, Ready Controller Signals
Each 0.1 cap should be placed new to the VXX... and GND Pains
20 MHz Crystals for MCU Clock
PWM Signals
This controller will be an Open-loop first, it will not be able to regulate the voltage 120Vrms. It will start there with no load and then drop as load is added.
JTAG Connector
Optocoupler: Gate node precharge driver
Optocoupler: Gate node input protection sence
Each 0.1 cap should be placed new to the VDD and VSS Pains
GPIO High = precharge MOSFET ON GPIO Low = precharge MOSFET OFF
+3V3 logic Power

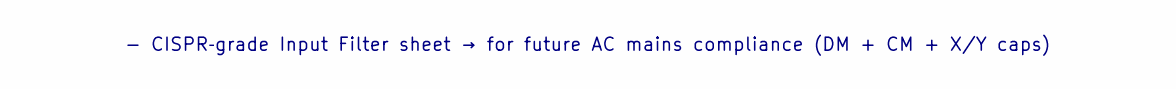
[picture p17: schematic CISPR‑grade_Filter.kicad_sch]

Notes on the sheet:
- CISPR‑grade Input Filter sheet → for future AC mains compliance (DM + CM + X/Y caps)

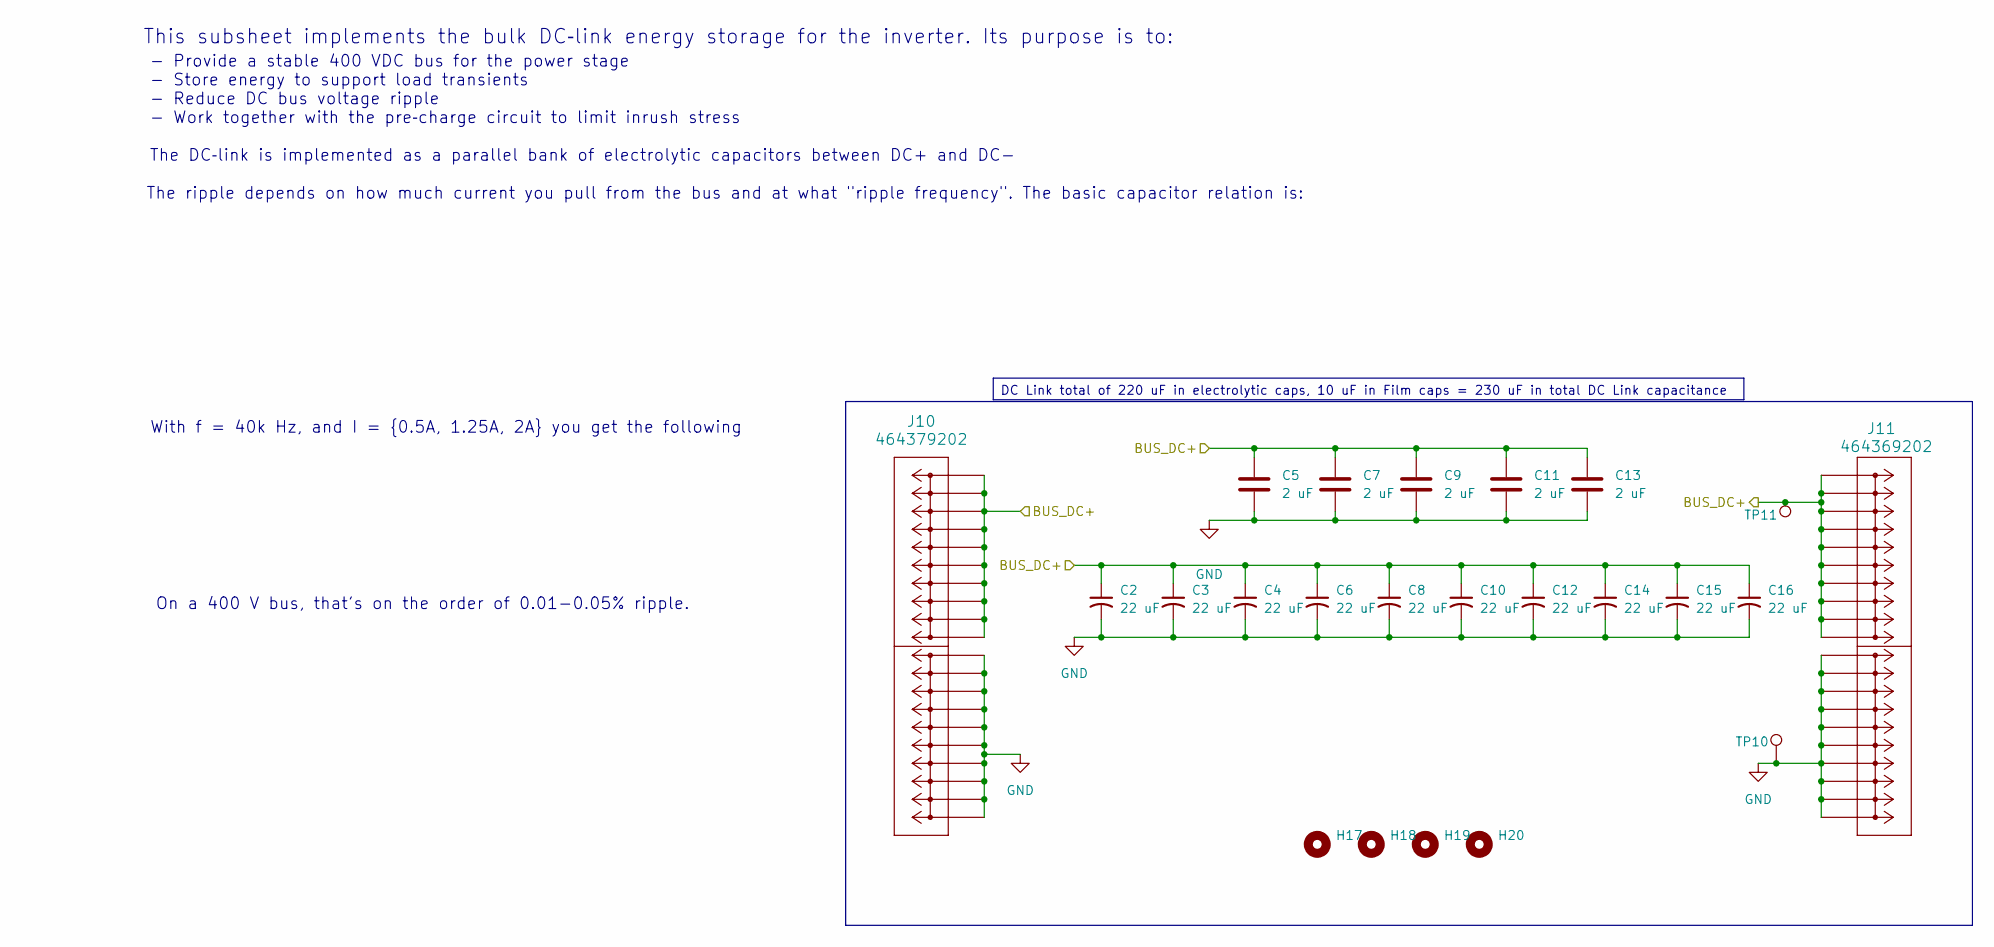
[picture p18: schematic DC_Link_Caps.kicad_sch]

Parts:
C2, C3, C4, C6, C8, C10, C12, C14, C15, C16: 22 uF; ESH226M500AL4AA
C5, C7, C9, C11, C13: 2 uF; MKP1848C52050JK2
H17, H18, H19, H20: MountingHole; MountingHole_2.2mm_M2
J10: 464379202; 46437-900_02
J11: 464369202; 46436-900_02
TP10: 5281
TP11: 5277

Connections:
/DC_Link_Caps/BUS_DC+: C2.1, C3.1, C4.1, C5.1, C6.1, C7.1, C8.1, C9.1, C10.1, C11.1, C12.1, C13.1, C14.1, C15.1, C16.1, J10.P2_1, J10.P2_2, J10.P2_3, J10.P2_4, J10.P2_5, J10.P2_6, J10.P2_7, J10.P2_8, J10.P2_9, J10.P2_10, J11.P1_1, J11.P1_2, J11.P1_3, J11.P1_4, J11.P1_5, J11.P1_6, J11.P1_7, J11.P1_8, J11.P1_9, J11.P1_10, TP11.1 (1_1); also elsewhere on the board
GND: C2.2, C3.2, C4.2, C5.2, C6.2, C7.2, C8.2, C9.2, C10.2, C11.2, C12.2, C13.2, C14.2, C15.2, C16.2, J10.P1_1, J10.P1_2, J10.P1_3, J10.P1_4, J10.P1_5, J10.P1_6, J10.P1_7, J10.P1_8, J10.P1_9, J10.P1_10, J11.P2_1, J11.P2_2, J11.P2_3, J11.P2_4, J11.P2_5, J11.P2_6, J11.P2_7, J11.P2_8, J11.P2_9, J11.P2_10, TP10.1 (1_1); also elsewhere on the board

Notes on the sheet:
- Provide a stable 400 VDC bus for the power stage - Store energy to support load transients - Reduce DC bus voltage ripple - Work together with the pre‑charge circuit to limit inrush stress The DC‑link is implemented as a parallel bank of electrolytic capacitors between DC+ and DC−
With f = 40k Hz, and I = {0.5A, 1.25A, 2A} you get the following
This subsheet implements the bulk DC‑link energy storage for the inverter. Its purpose is to:
On a 400 V bus, that's on the order of 0.01-0.05% ripple.
The ripple depends on how much current you pull from the bus and at what "ripple frequency". The basic capacitor relation is:
DC Link total of 220 uF in electrolytic caps, 10 uF in Film caps = 230 uF in total DC Link capacitance

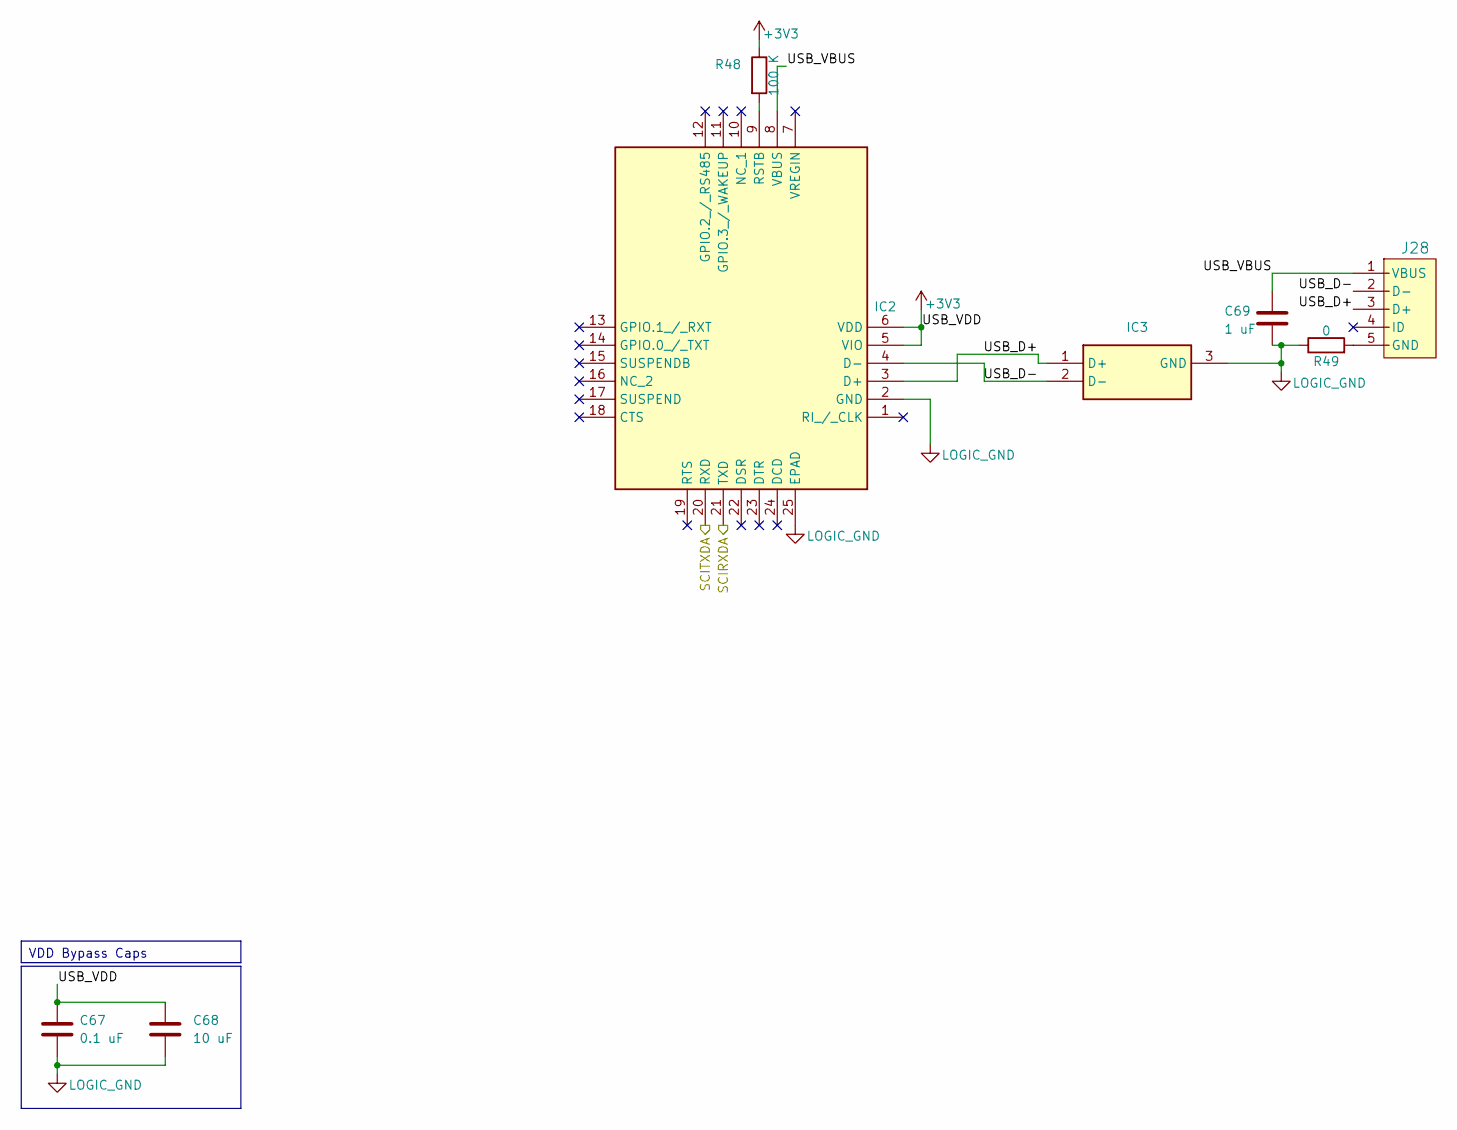
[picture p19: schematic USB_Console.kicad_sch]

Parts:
C67: 0.1 uF; C_0805_2012Metric_Pad1.18x1.45mm_HandSolder
C68: 10 uF; C_0805_2012Metric_Pad1.18x1.45mm_HandSolder
C69: 1 uF; C_1206_3216Metric_Pad1.33x1.80mm_HandSolder
IC2: CP2102N-A02-GQFN24R; Mouser Part Number 634-CP2102NA02QFN24R
IC3: TPD2EUSB30ADRTR; Mouser Part Number 595-TPD2EUSB30ADRTR
J28: 1051330011; 105133-0011
R48: 100 K; R_1206_3216Metric_Pad1.30x1.75mm_HandSolder
R49: 0; R_1206_3216Metric_Pad1.30x1.75mm_HandSolder

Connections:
+3V3: C67.1, C68.1, IC2.5 (VIO), IC2.6 (VDD), R48.1; also elsewhere on the board
/Con_SCIRXDA: IC2.21 (TXD); also elsewhere on the board
/Con_SCITXDA: IC2.20 (RXD); also elsewhere on the board
/USB_Console/USB_D+: IC2.3 (D+), IC3.1 (D+), J28.3 (D+)
/USB_Console/USB_D-: IC2.4 (D-), IC3.2 (D-), J28.2 (D-)
/USB_Console/USB_VBUS: C69.1, IC2.8 (VBUS), J28.1 (VBUS)
LOGIC_GND: C67.2, C68.2, C69.2, IC2.2 (GND), IC2.25 (EPAD), IC3.3 (GND), R49.1; also elsewhere on the board
unnamed: IC2.9 (RSTB), R48.2
unnamed: J28.5 (GND), R49.2

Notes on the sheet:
VDD Bypass Caps

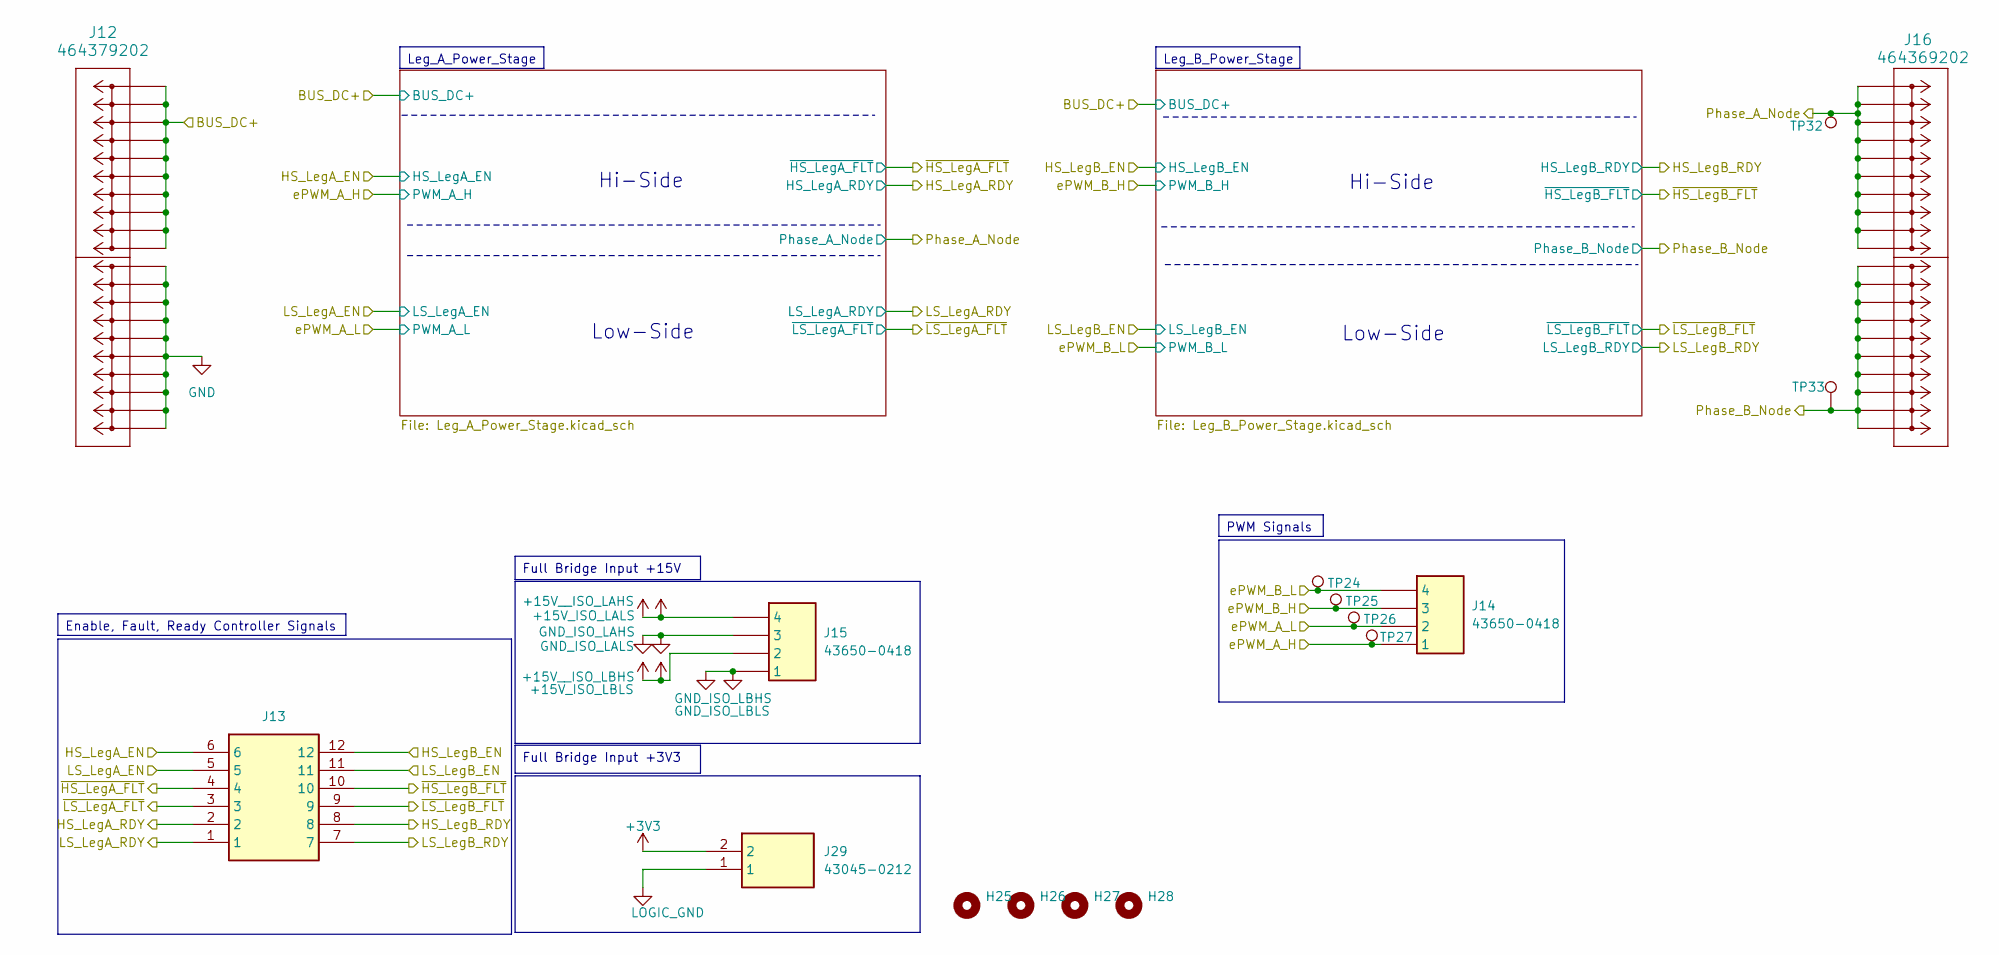
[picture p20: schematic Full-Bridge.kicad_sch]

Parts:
H25, H26, H27, H28: MountingHole; MountingHole_2.2mm_M2
J12: 464379202; 46437-900_02
J13: 43045-1212; Mouser Part Number 538-43045-1212
J14, J15: 43650-0418; 436500418; Mouser Part Number 538-43650-0418
J16: 464369202; 46436-900_02
J29: 43045-0212; Mouser Part Number 538-430-45-0212
TP24, TP25, TP26, TP27, TP32: 5277
TP33: 5281

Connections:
+3V3: J29.2; also elsewhere on the board
+15V_ISO_LALS: J15.4; also elsewhere on the board
+15V_ISO_LBLS: J15.2; also elsewhere on the board
/Con_EN_A_H: J13.6; also elsewhere on the board
/Con_EN_A_L: J13.5; also elsewhere on the board
/Con_EN_B_H: J13.12; also elsewhere on the board
/Con_EN_B_L: J13.11; also elsewhere on the board
/Con_FLT_A_H: J13.4; also elsewhere on the board
/Con_FLT_A_L: J13.3; also elsewhere on the board
/Con_FLT_B_H: J13.10; also elsewhere on the board
/Con_FLT_B_L: J13.9; also elsewhere on the board
/Con_PWM_A_H: J14.1, TP27.1 (1_1); also elsewhere on the board
/Con_PWM_A_L: J14.2, TP26.1 (1_1); also elsewhere on the board
/Con_PWM_B_H: J14.3, TP25.1 (1_1); also elsewhere on the board
/Con_PWM_B_L: J14.4, TP24.1 (1_1); also elsewhere on the board
/Con_RDY_A_H: J13.2; also elsewhere on the board
/Con_RDY_A_L: J13.1; also elsewhere on the board
/Con_RDY_B_H: J13.8; also elsewhere on the board
/Con_RDY_B_L: J13.7; also elsewhere on the board
/DC_Link_Caps/BUS_DC+: J12.P2_1, J12.P2_2, J12.P2_3, J12.P2_4, J12.P2_5, J12.P2_6, J12.P2_7, J12.P2_8, J12.P2_9, J12.P2_10; also elsewhere on the board
GND: J12.P1_1, J12.P1_2, J12.P1_3, J12.P1_4, J12.P1_5, J12.P1_6, J12.P1_7, J12.P1_8, J12.P1_9, J12.P1_10; also elsewhere on the board
GND_ISO_LAHS: J15.3, J16.P1_1, J16.P1_2, J16.P1_3, J16.P1_4, J16.P1_5, J16.P1_6, J16.P1_7, J16.P1_8, J16.P1_9, J16.P1_10, TP32.1 (1_1); also elsewhere on the board
GND_ISO_LBHS: J15.1, J16.P2_1, J16.P2_2, J16.P2_3, J16.P2_4, J16.P2_5, J16.P2_6, J16.P2_7, J16.P2_8, J16.P2_9, J16.P2_10, TP33.1 (1_1); also elsewhere on the board
LOGIC_GND: J29.1; also elsewhere on the board

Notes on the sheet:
Hi-Side
Low-Side
PWM Signals
Full Bridge Input +15V
Full Bridge Input +3V3
Leg_B_Power_Stage
Enable, Fault, Ready Controller Signals
Leg_A_Power_Stage

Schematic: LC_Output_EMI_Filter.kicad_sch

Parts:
C53: 6.8 uF; C4AF9BW4680T3FK; Manufacturer_Part_Number C4AF9BW4680T3FK
H29, H30, H31, H32: MountingHole; MountingHole_2.2mm_M2
J3: 23AH8786-Red
J4: 23AH8785-Black
J17: 464379202; 46437-900_02
L3, L4: 470 uH; 1140471KRC; Mouser Part Number 542-1140-471K-RC
R33: 6; CW005100R0JE12HE
TP3: 5277
TP4: 5281

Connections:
/Phase_A_Output: C53.1, C53.3, J3.1 (1_1), L3.2, R33.1, TP3.1 (1_1)
/Phase_B_Output: C53.2, C53.4, J4.1 (1_1), L4.2, R33.2, TP4.1 (1_1)
GND_ISO_LAHS: J17.P2_1, J17.P2_2, J17.P2_3, J17.P2_4, J17.P2_5, J17.P2_6, J17.P2_7, J17.P2_8, J17.P2_9, J17.P2_10, L3.1; also elsewhere on the board
GND_ISO_LBHS: J17.P1_1, J17.P1_2, J17.P1_3, J17.P1_4, J17.P1_5, J17.P1_6, J17.P1_7, J17.P1_8, J17.P1_9, J17.P1_10, L4.1; also elsewhere on the board

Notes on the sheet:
1. A floating 120 Vrms line‑to‑line output is a valid 120 V AC source Most people think "120 V" means "120 V from hot to neutral," but electrically: • Appliances only care about the voltage across their two input terminals. • They do not require one of those terminals to be neutral or earth‑referen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
LCL AC Output Filter

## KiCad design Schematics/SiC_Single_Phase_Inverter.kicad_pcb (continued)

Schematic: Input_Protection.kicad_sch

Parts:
C66: 0.1 uF; C_0805_2012Metric_Pad1.18x1.45mm_HandSolder
D6: P6KE500A-HF; D_DO-15_P12.70mm_Horizontal
D7: BZX84C15-7-F; SOT-23-3
F1: 0031.8322
H1, H2, H3, H4: MountingHole; MountingHole_2.2mm_M2
J1: 23AH8786-Red
J2: 23AH8785-Black
J23: 464369202; 46436-900_02
J24: 43650-0418; 436500418; Mouser Part Number 538-43650-0418
Q8: STB10NK60ZT4; TO-263-2
R44, R45: 499 K; R_1206_3216Metric_Pad1.30x1.75mm_HandSolder
R46: 47; R_1206_3216Metric_Pad1.30x1.75mm_HandSolder
R47: 100 K; R_1206_3216Metric_Pad1.30x1.75mm_HandSolder
TP1, TP67, TP69: 5277
TP2, TP68: 5281

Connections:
+VIN: F1.1, J1.1 (1_1), TP1.1 (1_1)
-VIN: J2.1 (1_1), Q8.2, TP2.1 (1_1)
/Con_Pro_Gate_node_output: C66.2, D7.1 (K), J24.4, R45.2, R46.2, R47.2, TP67.1 (1_1); also elsewhere on the board
/EMI_Input_Filter/+VIN_EMI: D6.1 (K), F1.2, J23.P1_1, J23.P1_2, J23.P1_3, J23.P1_4, J23.P1_5, J23.P1_6, J23.P1_7, J23.P1_8, J23.P1_9, J23.P1_10, J24.2, J24.3, R44.1, TP69.1 (1_1); also elsewhere on the board
GND: C66.1, D6.2 (A), D7.2 (A), J23.P2_1, J23.P2_2, J23.P2_3, J23.P2_4, J23.P2_5, J23.P2_6, J23.P2_7, J23.P2_8, J23.P2_9, J23.P2_10, J24.1, Q8.3, R47.1, TP68.1 (1_1); also elsewhere on the board
unnamed: Q8.1 (G), R46.1
unnamed: R44.2, R45.1

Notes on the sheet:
This stage protects the inverter from incorrect wiring, overcurrent faults, and high‑energy transients on the DC input. The protection chain consists of a series fuse on the positive rail, a low‑side N‑MOSFET used as an ideal‑diode reverse‑polarity protector, and a high‑voltage TVS diode across the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
Input Protection Overview
Protected Voltage and GPIO to Power Board
Input Protection: Fuse, Reverse-polarity, OC, Protection

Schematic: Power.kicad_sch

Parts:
H9, H10, H11, H12: MountingHole; MountingHole_2.2mm_M2
J25, J26, J27: 43650-0418; 436500418; Mouser Part Number 538-43650-0418
J30: 43045-0212; Mouser Part Number 538-430-45-0212
PS1, PS2: IRM-03-15
TP70, TP73, TP75: 5281
TP71, TP72, TP74: 5277
U5: TR05S3V3

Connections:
+3V3: J26.2, J30.2, TP71.1 (1_1), U5.3 (+VOUT); also elsewhere on the board
+15V_ISO_LALS: J27.4, PS1.16 (+VO), TP72.1 (1_1), U5.1 (+VIN); also elsewhere on the board
+15V_ISO_LBLS: J27.2, PS2.16 (+VO), TP74.1 (1_1); also elsewhere on the board
/Con_Pro_Gate_node_output: J25.4, J26.4; also elsewhere on the board
/EMI_Input_Filter/+VIN_EMI: J25.2, J25.3, PS1.1 (AC/L), PS2.1 (AC/L); also elsewhere on the board
GND: J25.1, J26.3, PS1.3 (AC/N), PS2.3 (AC/N); also elsewhere on the board
GND_ISO_LAHS: J27.3, PS1.14 (-VO), TP73.1 (1_1); also elsewhere on the board
GND_ISO_LBHS: J27.1, PS2.14 (-VO), TP75.1 (1_1); also elsewhere on the board
LOGIC_GND: J26.1, J30.1, TP70.1 (1_1), U5.2 (GND); also elsewhere on the board

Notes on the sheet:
Isolated Leg B Half Bridge: 15V Output
Isolated Leg A Half Bridge: 15V Output
Input Voltage From Protection Circuit
Power Supply +3V3 logic Power
Output to Full Bridge +3V3

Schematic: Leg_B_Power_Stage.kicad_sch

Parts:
C35, C36: 15 uF; C_1206_3216Metric_Pad1.33x1.80mm_HandSolder
C37, C38, C44, C47, C48, C51: 0.1 uF; C_0805_2012Metric_Pad1.18x1.45mm_HandSolder
C39, C40, C45, C52: 1 uF; C_1206_3216Metric_Pad1.33x1.80mm_HandSolder
C41, C42, C43, C46, C49, C50: 100 pF; C_0603_1608Metric_Pad1.08x0.95mm_HandSolder
D4, D5: BZX84C20-7-F; SOT-23-3
Q4, Q5: C3M0025065K
R19, R20: 100 K; R_1206_3216Metric_Pad1.30x1.75mm_HandSolder
R21, R22, R23, R24: 10; R_1206_3216Metric_Pad1.30x1.75mm_HandSolder
R25, R27, R28, R30, R31, R32: 5 K; R_1206_3216Metric_Pad1.30x1.75mm_HandSolder
R26, R29: 100; R_1206_3216Metric_Pad1.30x1.75mm_HandSolder
TP36, TP37: 5277
U3, U4: UCC21710QDWRQ1; Mouser Part Number 595-UCC21710QDWRQ1

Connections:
+3V3: C44.1, C45.1, C51.1, C52.1, R25.1, R27.1, R28.1, R30.1, R31.1, R32.1, U3.15 (VCC), U4.15 (VCC); also elsewhere on the board
+15V_ISO_LBLS: C35.1, C36.1, C37.1, C38.1, C39.1, C40.1, U3.5 (VDD), U4.5 (VDD); also elsewhere on the board
/Con_EN_B_H: C50.1, R27.2, U4.14 (~RST/EN); also elsewhere on the board
/Con_EN_B_L: C43.1, R25.2, U3.14 (~RST/EN); also elsewhere on the board
/Con_FLT_B_H: C49.1, R30.2, U4.13 (~FLT); also elsewhere on the board
/Con_FLT_B_L: C42.1, R28.2, U3.13 (~FLT); also elsewhere on the board
/Con_PWM_B_H: R29.2; also elsewhere on the board
/Con_PWM_B_L: R26.2; also elsewhere on the board
/Con_RDY_B_H: C46.1, R32.2, U4.12 (RDY); also elsewhere on the board
/Con_RDY_B_L: C41.1, R31.2, U3.12 (RDY); also elsewhere on the board
/DC_Link_Caps/BUS_DC+: Q4.1; also elsewhere on the board
/Full-Bridge/Leg_B_Power_Stage/LegB_HS_Gate: D4.1 (K), Q4.4, R19.1, R21.2, R22.2, TP36.1 (1_1), U4.7 (CLMPI)
/Full-Bridge/Leg_B_Power_Stage/LegB_HS_OUTH: R21.1, U4.4 (OUTH)
/Full-Bridge/Leg_B_Power_Stage/LegB_HS_OUTL: R22.1, U4.6 (OUTL)
/Full-Bridge/Leg_B_Power_Stage/LegB_LS_Gate: D5.1 (K), Q5.4, R20.1, R23.2, R24.2, TP37.1 (1_1), U3.7 (CLMPI)
/Full-Bridge/Leg_B_Power_Stage/LegB_LS_OUTH: R23.1, U3.4 (OUTH)
/Full-Bridge/Leg_B_Power_Stage/LegB_LS_OUTL: R24.1, U3.6 (OUTL)
GND: C36.2, C38.2, C40.2, D5.2 (A), Q5.2, Q5.3, R20.2, U3.1 (AIN), U3.2 (OC), U3.3 (COM); also elsewhere on the board
GND_ISO_LBHS: C35.2, C37.2, C39.2, D4.2 (A), Q4.2, Q4.3, Q5.1, R19.2, U3.8 (VEE), U4.1 (AIN), U4.2 (OC), U4.3 (COM), U4.8 (VEE); also elsewhere on the board
LOGIC_GND: C41.2, C42.2, C43.2, C44.2, C45.2, C46.2, C47.2, C48.2, C49.2, C50.2, C51.2, C52.2, U3.9 (GND), U3.11 (IN-), U4.9 (GND), U4.11 (IN-); also elsewhere on the board
unnamed: C47.1, R26.1, U3.10 (IN+)
unnamed: C48.1, R29.1, U4.10 (IN+)

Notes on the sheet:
Pick out 15 uF, 0.1 uF , and 1 uF cap and fill out footprint Before moving on to the Low Side for Leg A
Leg BH Bypass Caps
Leg B
Need a Isoulated DC-DC Converter for this. THe 15V output will be +15V_ISO_LALS and GND_ISO_LALS
R0ff
High Side
Ron
Leg BL Bypass Caps
Low Side
Ceramic
Need a Isoulated DC-DC Converter for this. THe 15V output will be +15V_ISO_LAHS and GND_ISO_LAHS

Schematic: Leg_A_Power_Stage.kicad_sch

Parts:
C17, C18: 15 uF; C_1206_3216Metric_Pad1.33x1.80mm_HandSolder
C19, C20, C26, C29, C30, C33: 0.1 uF; C_0805_2012Metric_Pad1.18x1.45mm_HandSolder
C21, C22, C27, C34: 1 uF; C_1206_3216Metric_Pad1.33x1.80mm_HandSolder
C23, C24, C25, C28, C31, C32: 100 pF; C_0603_1608Metric_Pad1.08x0.95mm_HandSolder
D2, D3: BZX84C20-7-F; SOT-23-3
Q2, Q3: C3M0025065K
R5, R6: 100 K; R_1206_3216Metric_Pad1.30x1.75mm_HandSolder
R7, R8, R9, R10: 10; R_1206_3216Metric_Pad1.30x1.75mm_HandSolder
R11, R13, R14, R16, R17, R18: 5 K; R_1206_3216Metric_Pad1.30x1.75mm_HandSolder
R12, R15: 100; R_1206_3216Metric_Pad1.30x1.75mm_HandSolder
TP34, TP35: 5277
U1, U2: UCC21710QDWRQ1; Mouser Part Number 595-UCC21710QDWRQ1

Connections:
+3V3: C26.1, C27.1, C33.1, C34.1, R11.1, R13.1, R14.1, R16.1, R17.1, R18.1, U1.15 (VCC), U2.15 (VCC); also elsewhere on the board
+15V_ISO_LALS: C17.1, C18.1, C19.1, C20.1, C21.1, C22.1, U1.5 (VDD), U2.5 (VDD); also elsewhere on the board
/Con_EN_A_H: C32.1, R13.2, U2.14 (~RST/EN); also elsewhere on the board
/Con_EN_A_L: C25.1, R11.2, U1.14 (~RST/EN); also elsewhere on the board
/Con_FLT_A_H: C31.1, R16.2, U2.13 (~FLT); also elsewhere on the board
/Con_FLT_A_L: C24.1, R14.2, U1.13 (~FLT); also elsewhere on the board
/Con_PWM_A_H: R15.2; also elsewhere on the board
/Con_PWM_A_L: R12.2; also elsewhere on the board
/Con_RDY_A_H: C28.1, R18.2, U2.12 (RDY); also elsewhere on the board
/Con_RDY_A_L: C23.1, R17.2, U1.12 (RDY); also elsewhere on the board
/DC_Link_Caps/BUS_DC+: Q2.1; also elsewhere on the board
/Full-Bridge/Leg_A_Power_Stage/LegA_HS_Gate: D2.1 (K), Q2.4, R5.1, R7.2, R8.2, TP34.1 (1_1), U2.7 (CLMPI)
/Full-Bridge/Leg_A_Power_Stage/LegA_HS_OUTH: R7.1, U2.4 (OUTH)
/Full-Bridge/Leg_A_Power_Stage/LegA_HS_OUTL: R8.1, U2.6 (OUTL)
/Full-Bridge/Leg_A_Power_Stage/LegA_LS_Gate: D3.1 (K), Q3.4, R6.1, R9.2, R10.2, TP35.1 (1_1), U1.7 (CLMPI)
/Full-Bridge/Leg_A_Power_Stage/LegA_LS_OUTH: R9.1, U1.4 (OUTH)
/Full-Bridge/Leg_A_Power_Stage/LegA_LS_OUTL: R10.1, U1.6 (OUTL)
GND: C18.2, C20.2, C22.2, D3.2 (A), Q3.2, Q3.3, R6.2, U1.1 (AIN), U1.2 (OC), U1.3 (COM); also elsewhere on the board
GND_ISO_LAHS: C17.2, C19.2, C21.2, D2.2 (A), Q2.2, Q2.3, Q3.1, R5.2, U1.8 (VEE), U2.1 (AIN), U2.2 (OC), U2.3 (COM), U2.8 (VEE); also elsewhere on the board
LOGIC_GND: C23.2, C24.2, C25.2, C26.2, C27.2, C28.2, C29.2, C30.2, C31.2, C32.2, C33.2, C34.2, U1.9 (GND), U1.11 (IN-), U2.9 (GND), U2.11 (IN-); also elsewhere on the board
unnamed: C29.1, R12.1, U1.10 (IN+)
unnamed: C30.1, R15.1, U2.10 (IN+)

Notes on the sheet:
Ron
R0ff
Low Side
Ceramic
High Side
Leg AL Bypass Caps
Leg AH Bypass Caps
Leg A

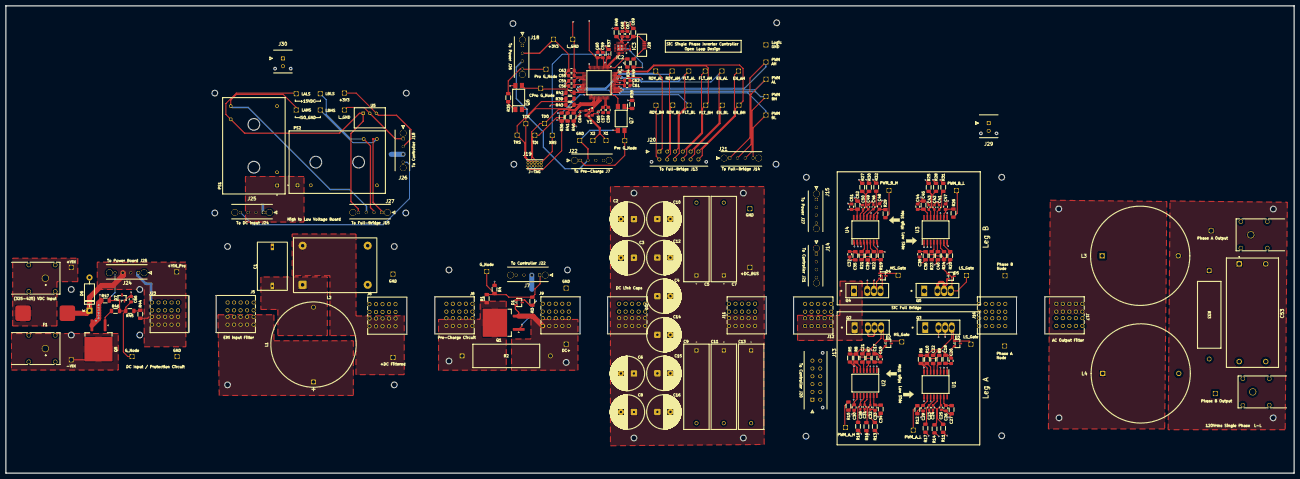
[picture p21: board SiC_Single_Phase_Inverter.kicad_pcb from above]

Board: 2 copper layers, 494.6 x 179.4 mm, 271 parts (0 on the bottom side), 74 nets.

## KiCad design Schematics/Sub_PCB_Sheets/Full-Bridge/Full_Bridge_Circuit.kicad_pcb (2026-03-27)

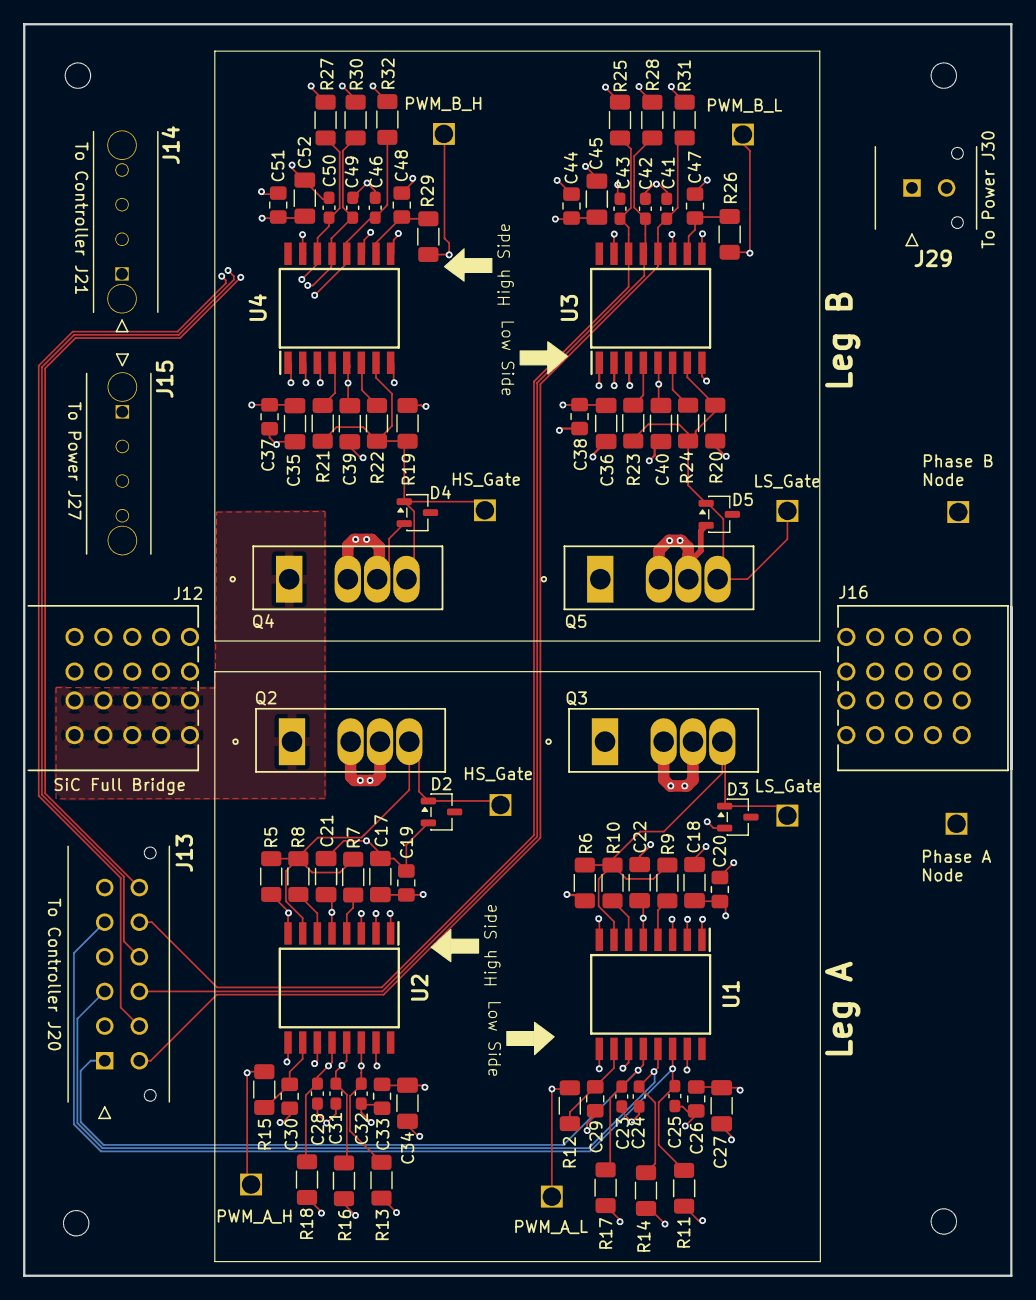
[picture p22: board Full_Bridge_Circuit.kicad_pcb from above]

Board: 4 copper layers, 85.5 x 108.4 mm, 96 parts (0 on the bottom side), 40 nets.

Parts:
C17, C18, C35, C36: 15 uF; C_1206_3216Metric_Pad1.33x1.80mm_HandSolder
C19, C20, C26, C29, C30, C33, C37, C38, C44, C47, C48, C51: 0.1 uF; C_0805_2012Metric_Pad1.18x1.45mm_HandSolder
C21, C22, C27, C34, C39, C40, C45, C52: 1 uF; C_1206_3216Metric_Pad1.33x1.80mm_HandSolder
C23, C24, C25, C28, C31, C32, C41, C42, C43, C46, C49, C50: 100 pF; C_0603_1608Metric_Pad1.08x0.95mm_HandSolder
D2, D3, D4, D5: BZX84C20-7-F; SOT-23-3
H25, H26, H27, H28: MountingHole; MountingHole_2.2mm_M2
J12: 464379202; 46437-900_02
J13: 43045-1212
J14, J15: 43650-0418; 436500418
J16: 464369202; 46436-900_02
J29: 43045-0212
Q2, Q3, Q4, Q5: TO-247-4_CRW; C3M0025065K
R5, R6, R19, R20: 100 K; R_1206_3216Metric_Pad1.30x1.75mm_HandSolder
R7, R8, R9, R10, R21, R22, R23, R24: 10; R_1206_3216Metric_Pad1.30x1.75mm_HandSolder
R11, R13, R14, R16, R17, R18, R25, R27, R28, R30, R31, R32: 5 K; R_1206_3216Metric_Pad1.30x1.75mm_HandSolder
R12, R15, R26, R29: 100; R_1206_3216Metric_Pad1.30x1.75mm_HandSolder
TP24, TP25, TP26, TP27, TP32, TP34, TP35, TP36, TP37: 5277
TP33: 5281
U1, U2, U3, U4: SOIC127P1030X265-16N; UCC21710QDWRQ1

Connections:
+3V3: C26.1, C27.1, C33.1, C34.1, C44.1, C45.1, C51.1, C52.1, J29.2, R11.1, R13.1, R14.1, R16.1, R17.1, R18.1, R25.1, R27.1, R28.1, R30.1, R31.1, R32.1, U1.15 (VCC), U2.15 (VCC), U3.15 (VCC), U4.15 (VCC)
+15V_ISO_LALS: C17.1, C18.1, C19.1, C20.1, C21.1, C22.1, J15.4, U1.5 (VDD), U2.5 (VDD)
+15V_ISO_LBLS: C35.1, C36.1, C37.1, C38.1, C39.1, C40.1, J15.2, U3.5 (VDD), U4.5 (VDD)
/Con_EN_A_H: C32.1, J13.6, R13.2, U2.14 (~RST/EN)
/Con_EN_A_L: C25.1, J13.5, R11.2, U1.14 (~RST/EN)
/Con_EN_B_H: C50.1, J13.12, R27.2, U4.14 (~RST/EN)
/Con_EN_B_L: C43.1, J13.11, R25.2, U3.14 (~RST/EN)
/Con_FLT_A_H: C31.1, J13.4, R16.2, U2.13 (~FLT)
/Con_FLT_A_L: C24.1, J13.3, R14.2, U1.13 (~FLT)
/Con_FLT_B_H: C49.1, J13.10, R30.2, U4.13 (~FLT)
/Con_FLT_B_L: C42.1, J13.9, R28.2, U3.13 (~FLT)
/Con_PWM_A_H: J14.1, R15.2, TP27.1 (1_1)
/Con_PWM_A_L: J14.2, R12.2, TP26.1 (1_1)
/Con_PWM_B_H: J14.3, R29.2, TP25.1 (1_1)
/Con_PWM_B_L: J14.4, R26.2, TP24.1 (1_1)
/Con_RDY_A_H: C28.1, J13.2, R18.2, U2.12 (RDY)
/Con_RDY_A_L: C23.1, J13.1, R17.2, U1.12 (RDY)
/Con_RDY_B_H: C46.1, J13.8, R32.2, U4.12 (RDY)
/Con_RDY_B_L: C41.1, J13.7, R31.2, U3.12 (RDY)
/DC_Link_Caps/BUS_DC+: J12.P2_1, J12.P2_2, J12.P2_3, J12.P2_4, J12.P2_5, J12.P2_6, J12.P2_7, J12.P2_8, J12.P2_9, J12.P2_10, Q2.1, Q4.1
/Full-Bridge/Leg_A_Power_Stage/LegA_HS_Gate: D2.1 (K), Q2.4, R5.1, R7.2, R8.2, TP34.1 (1_1), U2.7 (CLMPI)
/Full-Bridge/Leg_A_Power_Stage/LegA_HS_OUTH: R7.1, U2.4 (OUTH)
/Full-Bridge/Leg_A_Power_Stage/LegA_HS_OUTL: R8.1, U2.6 (OUTL)
/Full-Bridge/Leg_A_Power_Stage/LegA_LS_Gate: D3.1 (K), Q3.4, R6.1, R9.2, R10.2, TP35.1 (1_1), U1.7 (CLMPI)
/Full-Bridge/Leg_A_Power_Stage/LegA_LS_OUTH: R9.1, U1.4 (OUTH)
/Full-Bridge/Leg_A_Power_Stage/LegA_LS_OUTL: R10.1, U1.6 (OUTL)
/Full-Bridge/Leg_B_Power_Stage/LegB_HS_Gate: D4.1 (K), Q4.4, R19.1, R21.2, R22.2, TP36.1 (1_1), U4.7 (CLMPI)
/Full-Bridge/Leg_B_Power_Stage/LegB_HS_OUTH: R21.1, U4.4 (OUTH)
/Full-Bridge/Leg_B_Power_Stage/LegB_HS_OUTL: R22.1, U4.6 (OUTL)
/Full-Bridge/Leg_B_Power_Stage/LegB_LS_Gate: D5.1 (K), Q5.4, R20.1, R23.2, R24.2, TP37.1 (1_1), U3.7 (CLMPI)
/Full-Bridge/Leg_B_Power_Stage/LegB_LS_OUTH: R23.1, U3.4 (OUTH)
/Full-Bridge/Leg_B_Power_Stage/LegB_LS_OUTL: R24.1, U3.6 (OUTL)
GND: C18.2, C20.2, C22.2, C36.2, C38.2, C40.2, D3.2 (A), D5.2 (A), J12.P1_1, J12.P1_2, J12.P1_3, J12.P1_4, J12.P1_5, J12.P1_6, J12.P1_7, J12.P1_8, J12.P1_9, J12.P1_10, Q3.2, Q3.3, Q5.2, Q5.3, R6.2, R20.2, U1.1 (AIN), U1.2 (OC), U1.3 (COM), U3.1 (AIN), U3.2 (OC), U3.3 (COM)
GND_ISO_LAHS: C17.2, C19.2, C21.2, D2.2 (A), J15.3, J16.P1_1, J16.P1_2, J16.P1_3, J16.P1_4, J16.P1_5, J16.P1_6, J16.P1_7, J16.P1_8, J16.P1_9, J16.P1_10, Q2.2, Q2.3, Q3.1, R5.2, TP32.1 (1_1), U1.8 (VEE), U2.1 (AIN), U2.2 (OC), U2.3 (COM), U2.8 (VEE)
GND_ISO_LBHS: C35.2, C37.2, C39.2, D4.2 (A), J15.1, J16.P2_1, J16.P2_2, J16.P2_3, J16.P2_4, J16.P2_5, J16.P2_6, J16.P2_7, J16.P2_8, J16.P2_9, J16.P2_10, Q4.2, Q4.3, Q5.1, R19.2, TP33.1 (1_1), U3.8 (VEE), U4.1 (AIN), U4.2 (OC), U4.3 (COM), U4.8 (VEE)
LOGIC_GND: C23.2, C24.2, C25.2, C26.2, C27.2, C28.2, C29.2, C30.2, C31.2, C32.2, C33.2, C34.2, C41.2, C42.2, C43.2, C44.2, C45.2, C46.2, C47.2, C48.2, C49.2, C50.2, C51.2, C52.2, J29.1, U1.9 (GND), U1.11 (IN-), U2.9 (GND), U2.11 (IN-), U3.9 (GND), U3.11 (IN-), U4.9 (GND), U4.11 (IN-)
unnamed: C29.1, R12.1, U1.10 (IN+)
unnamed: C30.1, R15.1, U2.10 (IN+)
unnamed: C47.1, R26.1, U3.10 (IN+)
unnamed: C48.1, R29.1, U4.10 (IN+)

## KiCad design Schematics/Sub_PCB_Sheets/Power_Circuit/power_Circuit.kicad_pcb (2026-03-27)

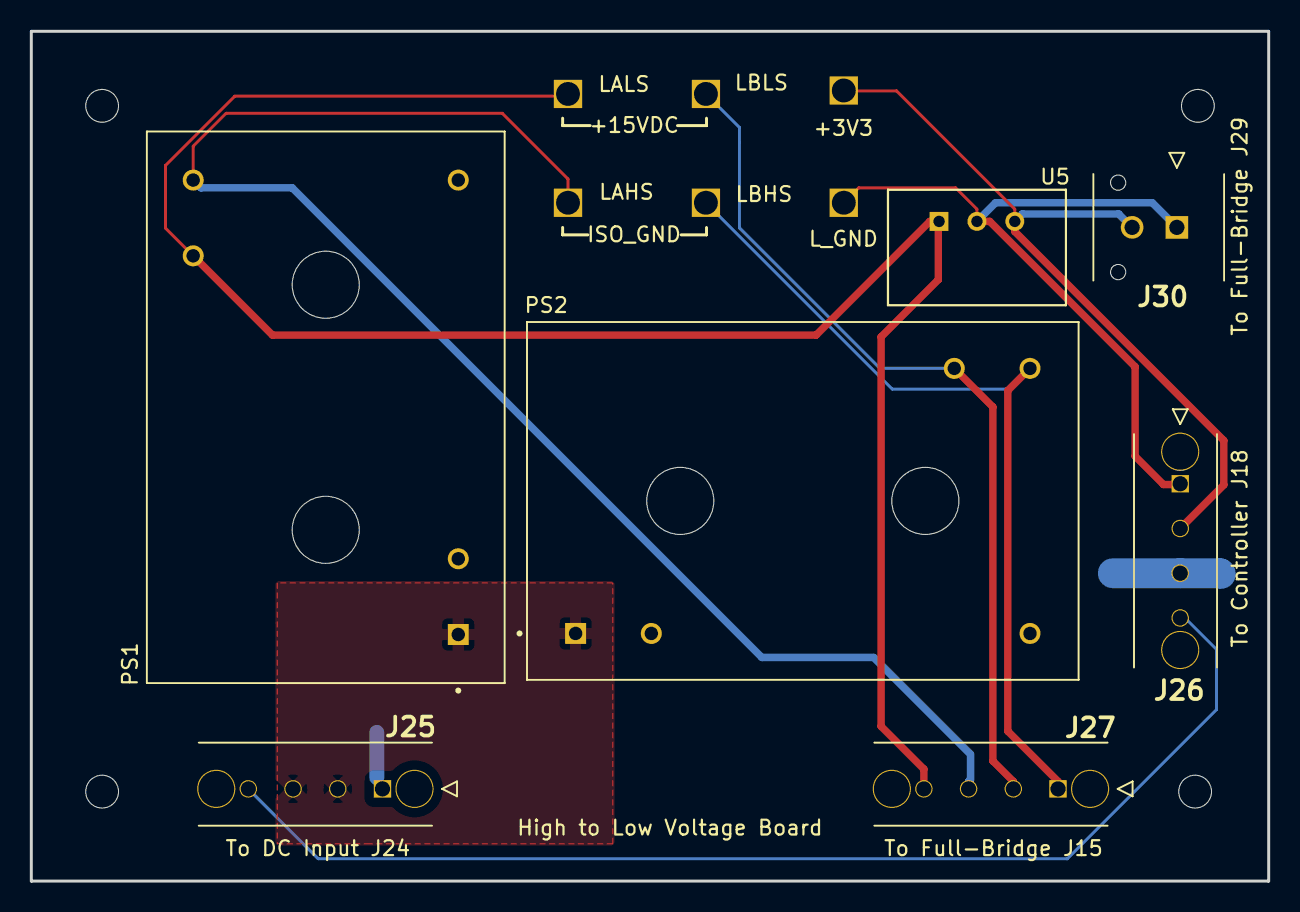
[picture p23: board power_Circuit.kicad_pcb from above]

Board: 2 copper layers, 83.0 x 57.0 mm, 17 parts (0 on the bottom side), 9 nets.

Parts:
H9, H10, H11, H12: MountingHole; MountingHole_2.2mm_M2
J25, J26, J27: 43650-0418; 436500418
J30: 43045-0212
PS1, PS2: IRM-03-15
TP70, TP73, TP75: 5281
TP71, TP72, TP74: 5277
U5: TR05S3V3

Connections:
+3V3: J26.2, J30.2, TP71.1 (1_1), U5.3 (+VOUT)
+15V_ISO_LALS: J27.4, PS1.16 (+VO), TP72.1 (1_1), U5.1 (+VIN)
+15V_ISO_LBLS: J27.2, PS2.16 (+VO), TP74.1 (1_1)
/Con_Pro_Gate_node_output: J25.4, J26.4
/EMI_Input_Filter/+VIN_EMI: J25.2, J25.3, PS1.1 (AC/L), PS2.1 (AC/L)
GND: J25.1, J26.3, PS1.3 (AC/N), PS2.3 (AC/N)
GND_ISO_LAHS: J27.3, PS1.14 (-VO), TP73.1 (1_1)
GND_ISO_LBHS: J27.1, PS2.14 (-VO), TP75.1 (1_1)
LOGIC_GND: J26.1, J30.1, TP70.1 (1_1), U5.2 (GND)

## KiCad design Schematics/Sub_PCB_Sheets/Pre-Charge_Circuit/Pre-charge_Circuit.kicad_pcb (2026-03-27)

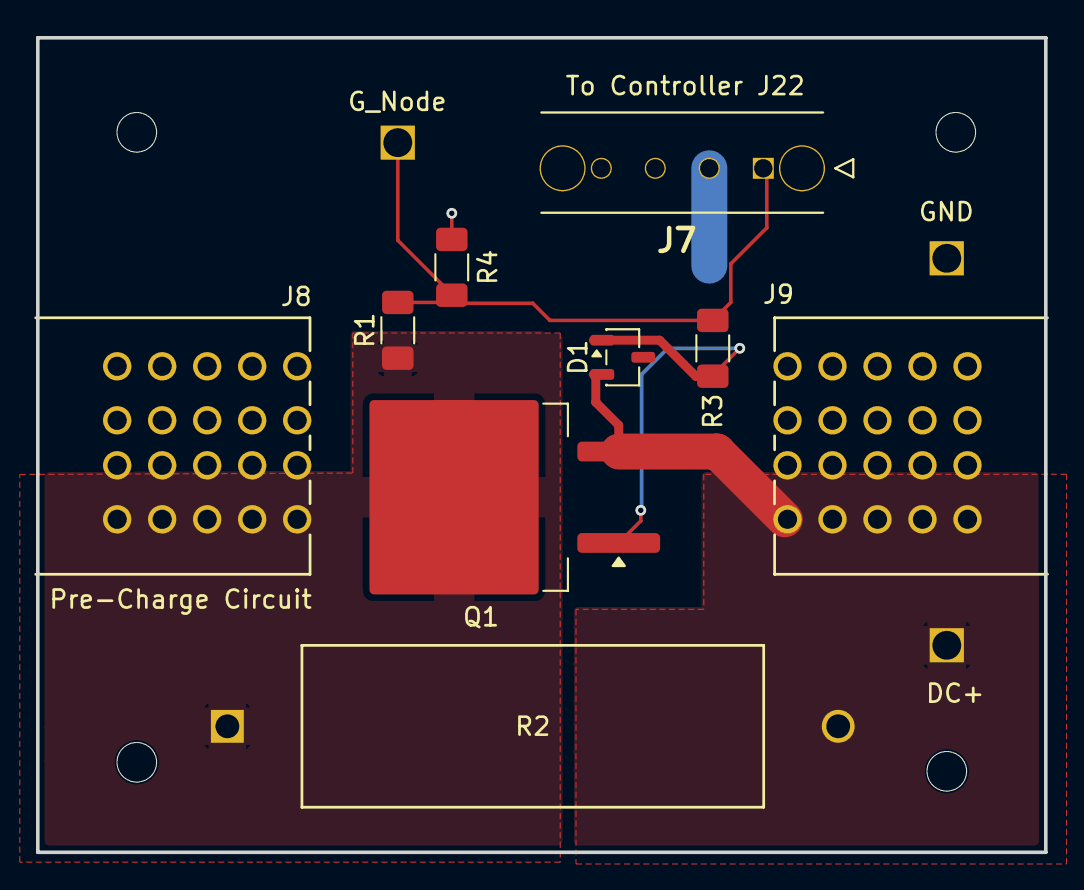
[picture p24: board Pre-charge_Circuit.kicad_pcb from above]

Board: 2 copper layers, 56.0 x 45.2 mm, 16 parts (0 on the bottom side), 5 nets.

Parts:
D1: BZX84C15-7-F; SOT-23-3
H13, H14, H15, H16: MountingHole; MountingHole_2.2mm_M2
J7: 43650-0418; 436500418
J8: 464379202; 46437-900_02
J9: 464369202; 46436-900_02
Q1: STB10NK60ZT4; TO-263-2
R1: 499 K; R_1206_3216Metric_Pad1.30x1.75mm_HandSolder
R2: CW005100R0JE12HE
R3: 47; R_1206_3216Metric_Pad1.30x1.75mm_HandSolder
R4: 100 K; R_1206_3216Metric_Pad1.30x1.75mm_HandSolder
TP7, TP8: 5277
TP9: 5281

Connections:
/Con_Gate_node_prech: J7.1, R1.2, R3.2, R4.1, TP7.1 (1_1)
/DC_Link_Caps/BUS_DC+: D1.2 (A), J9.P1_1, J9.P1_2, J9.P1_3, J9.P1_4, J9.P1_5, J9.P1_6, J9.P1_7, J9.P1_8, J9.P1_9, J9.P1_10, Q1.3, R2.2, TP8.1 (1_1)
/EMI_Input_Filter/BUS+_Filtered: J8.P2_1, J8.P2_2, J8.P2_3, J8.P2_4, J8.P2_5, J8.P2_6, J8.P2_7, J8.P2_8, J8.P2_9, J8.P2_10, Q1.2, R1.1, R2.1
GND: J7.2, J8.P1_1, J8.P1_2, J8.P1_3, J8.P1_4, J8.P1_5, J8.P1_6, J8.P1_7, J8.P1_8, J8.P1_9, J8.P1_10, J9.P2_1, J9.P2_2, J9.P2_3, J9.P2_4, J9.P2_5, J9.P2_6, J9.P2_7, J9.P2_8, J9.P2_9, J9.P2_10, R4.2, TP9.1 (1_1)
unnamed: D1.1 (K), Q1.1 (G), R3.1

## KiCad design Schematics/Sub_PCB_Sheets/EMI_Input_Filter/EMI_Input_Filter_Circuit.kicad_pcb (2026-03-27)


Board: 2 copper layers, 73.6 x 64.0 mm, 11 parts (0 on the bottom side), 4 nets, no tracks yet.

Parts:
C1: 1 uF; R71PI410050H6K
H5, H6, H7, H8: MountingHole; MountingHole_2.2mm_M2
J5: 464379202; 46437-900_02
J6: 464369202; 46436-900_02
L1: 47 uH; 2300HT_470
L2: 2.2 mH; 7448258022
TP5: 5277
TP6: 5281

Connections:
/EMI_Input_Filter/+VIN_EMI: J5.P2_1, J5.P2_2, J5.P2_3, J5.P2_4, J5.P2_5, J5.P2_6, J5.P2_7, J5.P2_8, J5.P2_9, J5.P2_10, L1.1
/EMI_Input_Filter/BUS+_Filtered: J6.P1_1, J6.P1_2, J6.P1_3, J6.P1_4, J6.P1_5, J6.P1_6, J6.P1_7, J6.P1_8, J6.P1_9, J6.P1_10, L2.4, TP5.1 (1_1)
/EMI_Input_Filter/BUS+_RAW: C1.1, L1.2, L2.1
GND: C1.2, J5.P1_1, J5.P1_2, J5.P1_3, J5.P1_4, J5.P1_5, J5.P1_6, J5.P1_7, J5.P1_8, J5.P1_9, J5.P1_10, J6.P2_1, J6.P2_2, J6.P2_3, J6.P2_4, J6.P2_5, J6.P2_6, J6.P2_7, J6.P2_8, J6.P2_9, J6.P2_10, L2.2, L2.3, TP6.1 (1_1)

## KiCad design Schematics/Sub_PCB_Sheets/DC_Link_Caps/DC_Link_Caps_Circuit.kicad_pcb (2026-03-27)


Board: 2 copper layers, 62.5 x 100.5 mm, 23 parts (0 on the bottom side), 2 nets, no tracks yet.

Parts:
C2, C3, C4, C6, C8, C10, C12, C14, C15, C16: 22 uF; ESH226M500AL4AA
C5, C7, C9, C11, C13: 2 uF; MKP1848C52050JK2
H17, H18, H19, H20: MountingHole; MountingHole_2.2mm_M2
J10: 464379202; 46437-900_02
J11: 464369202; 46436-900_02
TP10: 5281
TP11: 5277

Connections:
/DC_Link_Caps/BUS_DC+: C2.1, C3.1, C4.1, C5.1, C6.1, C7.1, C8.1, C9.1, C10.1, C11.1, C12.1, C13.1, C14.1, C15.1, C16.1, J10.P2_1, J10.P2_2, J10.P2_3, J10.P2_4, J10.P2_5, J10.P2_6, J10.P2_7, J10.P2_8, J10.P2_9, J10.P2_10, J11.P1_1, J11.P1_2, J11.P1_3, J11.P1_4, J11.P1_5, J11.P1_6, J11.P1_7, J11.P1_8, J11.P1_9, J11.P1_10, TP11.1 (1_1)
GND: C2.2, C3.2, C4.2, C5.2, C6.2, C7.2, C8.2, C9.2, C10.2, C11.2, C12.2, C13.2, C14.2, C15.2, C16.2, J10.P1_1, J10.P1_2, J10.P1_3, J10.P1_4, J10.P1_5, J10.P1_6, J10.P1_7, J10.P1_8, J10.P1_9, J10.P1_10, J11.P2_1, J11.P2_2, J11.P2_3, J11.P2_4, J11.P2_5, J11.P2_6, J11.P2_7, J11.P2_8, J11.P2_9, J11.P2_10, TP10.1 (1_1)

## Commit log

2026-02-25 [SiC Inverter WIP]
    - Deleted backup files
    - changed symbol and footprint lib locations
    - added text discription explaining the DC link sub sheet and emi input
    filter subsheet
    - Added Vin+,- Black and Red connector
    [23AH8785_Black.stp, Connectors.kicad_sch, DC_Link_Caps.kicad_sch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]
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2026-02-28 Work in progress
    - Added new parts to PCB to check 3d models
    - Added input protection sheet
    - Added TVS, N-Channel MOSFET, Zensor, and resiters to protection
    circuit
    - Added datasheets for new parts
    - Added circuit GND
    [EMI_Input_Filter.kicad_sch, Input_Protection.kicad_sch, SiC_Single_Phase_Inverter.kicad_pcb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]
2026-03-03 [WIP - SIC Inverter]
    - Added 3d models for 3 parts
    - Added 3 new footprints for the 3 added parts
    - Changed footprint 23AH8785 and 86 Black and Red
    - Finished WIP with EMI, Input Protection, and Precharge
    - Added datasheet
    [C3M0025065K.stp, CW005100R0JE12HE.step, DC_Link_Caps.kicad_sch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]
2026-03-04 [WIP Full Bridge Leg A High Side]
    - Changed Footprint for Black and Red connectors to THP but no Pin
    number
    - Changed DC Link cap sub sheet to have a cleaner look
    - Change footprint in 1206 reister to head solder pads
    - WIP Full Bridge Leg A High Side
    [DC_Link_Caps.kicad_sch, Full-Bridge.kicad_sch, Input_Protection.kicad_sch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]
2026-03-05 [LEG A WIP]
    - moved circuits in Leg A HS and LS
    - Completed 90% of HS and LS for LEG A
    [Full-Bridge.kicad_sch, Leg_A_Power_Stage.kicad_sch, Leg_B_Power_Stage.kicad_sch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]
2026-03-06 Adding 100 pf caps to Leg A circuit, WIP texts
    [Full-Bridge.kicad_sch, Leg_A_Power_Stage.kicad_sch, Leg_B_Power_Stage.kicad_sch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]
2026-03-06 Copy past Leg A onto Leg B, Changed hames on both High/Low side to match Leg B
    [Leg_A_Power_Stage.kicad_sch, Leg_B_Power_Stage.kicad_sch, SiC_Single_Phase_Inverter.kicad_pcb]
2026-03-06 [WIP Full Bridge]
    - Finished Leg B and cleaned up sub sheets Leg A and Leg B
    - Added Hierarchical sheet pins for Leg A,B and Full Bridge
    - Added power schamtic for future use
    [Full-Bridge.kicad_sch, Leg_B_Power_Stage.kicad_sch, Power.kicad_sch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]
2026-03-07 Added Footprints for Cap size 15u, 1u, 0.1u and 100p
    [Leg_A_Power_Stage.kicad_sch, Leg_B_Power_Stage.kicad_sch, SiC_Single_Phase_Inverter.kicad_pcb]
2026-03-08 Added LCL filter to output EMI Filter
    [LC_Output_EMI_Filter.kicad_sch, SiC_Single_Phase_Inverter.kicad_sch]
2026-03-08 [WIP SiC Single Phase Inverter
    - Updated README.md
    - Added New Parts for Output filter L,C,R
    - Added datasheets for the new parts
    - Added 3D models for the new parts
    - Added new symbols and footprints for the L,C,R
    - Finished output filter
    [1140-471K-RC.stp, C4AF9BW4680T3FK.stp, Input_Protection.kicad_sch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]
2026-03-09 [WIP SiC Single Phase Inverter]
    - Added PCB to PCB Male and Female connectors
    - Added symbols, footprints and 3d models for the parts listed above
    - Added Male and Female connectors to input protection and input emi
    subsheets
    - Changed PCB editor to account for two edge cuts/ two sub circuits
    [0464369202.stp, 0464379202.stp, EMI_Input_Filter.kicad_sch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]
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2026-03-10 [WIP SiC Single Phase Inverter]
    - Added AC - DC converter for 15V isolated supply
    - Added 2x IRM-05 to the power sub sheet
    - Added 3D part for the IRM-05
    [IRM-03-15.step, Power.kicad_sch, SiC_Single_Phase_Inverter.kicad_sch]
2026-03-11 [WIP Single Phase SiC Inverter]
    - Added molex 4 pin pcb connector for +15V power
    - Added 3d model, symbol and footprint
    - Added datasheet for molex connector
    - Added Male and Female pcb - pcb connectors to all sub sheets
    [43650-0418.stp, Controller.kicad_sch, DC_Link_Caps.kicad_sch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]
2026-03-12 [WIP SiC Single Phase Inverter]
    - Updated README to have a Block Diagram
    - WIP Sub sheets Power, Controller
    - Added the F2800 controller to the project
    - Added the controller to the controller sub sheet
    - Added text for a 15V to 3V3 voltage converter
    [Controller.kicad_sch, F280049CPMSR.stp, Power.kicad_sch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]
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2026-03-13 [WIP Single Phase Inverter]
    - Changed all Refs within each sub sheet (Stripe)
    - Added 3V3 Power Supply off of 15V iso supply
    - Added footprint, symbol and 3d part
    - updated PCB with new part
    [Controller.kicad_sch, DC_Link_Caps.kicad_sch, EMI_Input_Filter.kicad_sch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]
2026-03-14 WIP: Work on Controller layout, and fixed some sheet text and positions
    [Controller.kicad_sch, Leg_A_Power_Stage.kicad_sch, Leg_B_Power_Stage.kicad_sch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]
2026-03-15 [WIP Controller Design]
    - Wired up all 64 Pins on the Controller
    - Added 3d models for connectors and Controller
    - Added data sheets for the newly added parts
    - wired connectors to controller to external PCB Boards
    - Updated Text fields
    [43045-1212.stp, ABM8-20.000MHZ-B2-T.stp, Controller.kicad_sch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]
2026-03-15 [WIP Controller Subsheet]
    - Added USB sub sheet to allow use of a USB connection to controller
    - Added USB parts for USB Circuit
    [105133-0011.stp, CP2102N-A02-GQFN24R.stp, Controller.kicad_sch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]
2026-03-16 [Milestone Compelted Controller and USB]
    - Added Test Points
    - Completed USB circuit to Controller
    - Wired up Controller
    - Added Connectors to Power Subsheet and 12pin from cotnroller to Full
    Bridge
    - Added 3d models for USB compoents
    - General fixes to subsheets
    [5277.stp, 5281.stp, Controller.kicad_sch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]
2026-03-17 [WIP Input Protection Circuit to Controller]
    - Added Gate node input protection pin to controller
    - Added optocoupler to input protection circuit
    - Added 3d model for PC817.....
    - Updated PCB to test out PCB modularity
    [Controller.kicad_sch, Input_Protection.kicad_sch, Leg_A_Power_Stage.kicad_sch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]
2026-03-17 Added Precharge Gate Driver to controller and per charge sub circuit
    [Controller.kicad_sch, Input_Protection.kicad_sch, Power.kicad_sch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]
2026-03-18 WIP PCB, Added Test Points, added icon file
    [Controller.kicad_sch, DC_Link_Caps.kicad_sch, EMI_Input_Filter.kicad_sch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]
2026-03-19 WIP PCB Design: Finished DC Input / Protection Circuit
    [EMI_Input_Filter.kicad_sch, Input_Protection.kicad_sch, LC_Output_EMI_Filter.kicad_sch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]
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2026-03-21 Finished PCB Layout and Tracing for Pre-Charge and DC Link Caps
    [Pre-Chrage_Inrush_Limiting.kicad_sch, SiC_Single_Phase_Inverter.kicad_pcb]
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2026-03-24 Fixing Full Bridge MOSFET ISO_GND to reference GND or DC-
    [Leg_A_Power_Stage.kicad_sch, Leg_B_Power_Stage.kicad_sch, SiC_Single_Phase_Inverter.kicad_pcb]
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2026-03-24 Milestone Finished WIP PCB for 7 PCBs, Set up folders for each PCB
    [0464369202.stp, 0464379202.stp, 105133-0011.stp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]
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2026-03-27 Finished Input EMI Filter circuit and completed Feb output files
    [EMI_Input_Filter_Circuit-B_Cu.gbr, EMI_Input_Filter_Circuit-B_Mask.gbr, EMI_Input_Filter_Circuit-B_Paste.gbr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]
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2026-03-27 Fixing Silkscreen on Full-Bridge
    [Full_Bridge_Circuit-B_Cu.gbr, Full_Bridge_Circuit-B_Mask.gbr, Full_Bridge_Circuit-B_Paste.gbr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]
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2026-04-09 Adding testing file for EMI Input Filter
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
